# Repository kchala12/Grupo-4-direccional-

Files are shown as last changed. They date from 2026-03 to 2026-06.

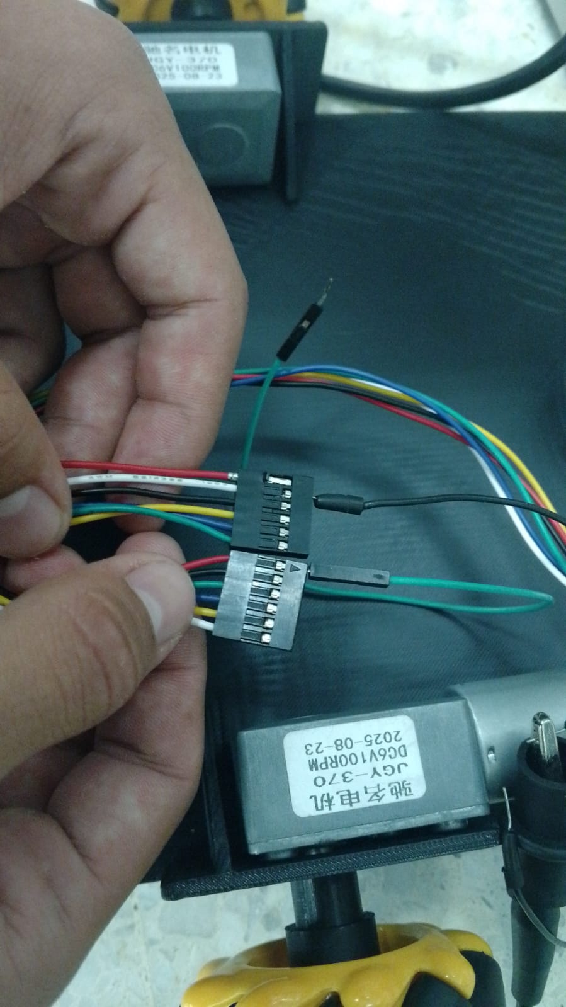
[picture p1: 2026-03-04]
Electronica/Imágenes Electrónica/motor defectuoso.jpeg

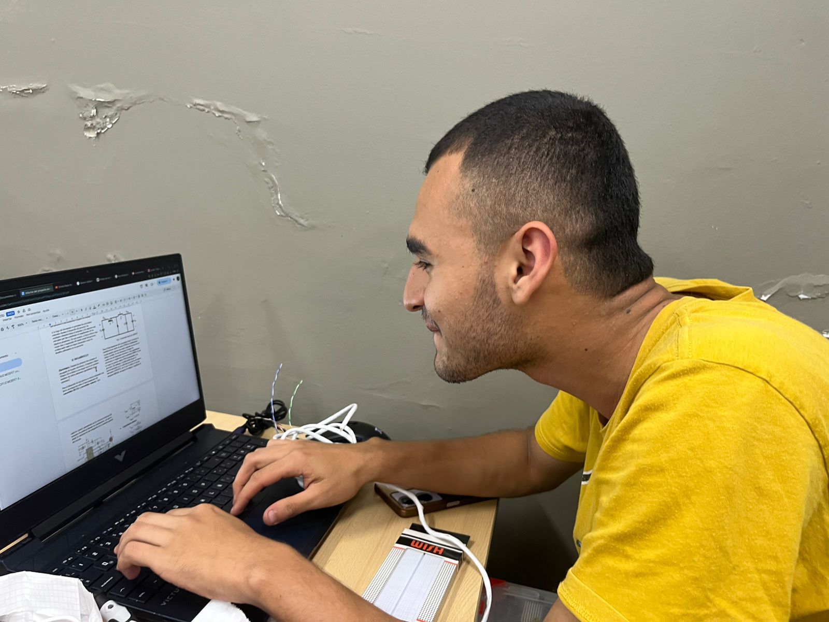
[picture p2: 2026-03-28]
Electronica/Imágenes Electrónica/TRABAJO CHALA.jpeg

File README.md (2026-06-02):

# Grupo-4-direccional

> **Robot Móvil Autónomo para Transporte Inteligente de Materiales**  
> Proyecto — Ingeniería Mecatrónica · Universidad Tecnológica de Pereira · 2026

---

## Descripción

Diseño y desarrollo de un **Vehículo Guiado Autónomo (AGV)** con visión artificial, capaz de transportar y descargar una carga de hasta **1 kg** a través de tres estaciones predefinidas, simulando operaciones logísticas en entornos industriales controlados.

El sistema utiliza **códigos QR** como referencias de navegación y una cámara **IMX219** para su detección en tiempo real, todo procesado sobre una **Raspberry Pi 5**.

---

## Objetivo

Desarrollar un robot funcional que complete de forma autónoma un ciclo de recolección y distribución de carga hacia tres estaciones destino con traccion diferencial, **sin intervención humana**, en un plazo de **16 semanas**.

---

##  Estructura del Repositorio

```
Grupo-4-direccional/
│
├── Documentacion/       # Matriz de documentos, informes y entregables
├── Electronica/         # Esquemas eléctricos, PCBs y firmware
├── Mecanica/            # Diseños CAD, planos y ensamblajes
├── src/                 # Código fuente principal (visión, navegación, control)
├── .gitignore
├── LICENSE
└── README.md
```
### 📁 [Documentacion](https://github.com/kchala12/Grupo-4-direccional-/tree/main/Documentacíon)
Contiene toda la documentación formal del proyecto: matriz de documentos, cronogramas, actas de reunión, informes de avance semanales y el informe final. También incluye presentaciones y entregables académicos requeridos por la universidad.
 
### 📁 [Electronica](https://github.com/kchala12/Grupo-4-direccional-/tree/main/Electronica)
Aquí se encuentran los esquemas eléctricos del sistema, diagramas de conexión de los componentes, diseños de PCB, selección y hoja de datos de los actuadores y drivers utilizados. También incluye el firmware de los microcontroladores encargados del control de motores y señales de los sensores.
 
### 📁 [Mecanica](https://github.com/kchala12/Grupo-4-direccional-/tree/main/Mecanica)
Contiene los diseños CAD del chasis del robot, planos técnicos de las piezas fabricadas o impresas en 3D, ensamblajes del sistema de tracción, soporte de carga y montaje de la cámara. 
 
### 📁 [src](https://github.com/kchala12/Grupo-4-direccional-/tree/main/src)
Código fuente principal del sistema autónomo. Incluye los módulos de visión artificial para la detección de códigos QR, algoritmos de navegación y control de trayectoria, lógica de gestión de estaciones y comunicación entre subsistemas. Todo desarrollado en Python sobre Raspberry Pi 5.
---

## 👥 Equipo

**Investigadores**
- Mateo Tabares Gil
- Federico Gómez Lotero
- Juan Sebastián Flórez Molina
- Kevin Andrés Chala González

**Director**
- Osiel Arbeláez Salazar

**Asesores**
- Angie Tatiana Rengifo Oviedo
- Carlos Andrés Rodríguez Pérez
- Edward Andrés González Ríos

---

## 🏛️ Institución

**Universidad Tecnológica de Pereira — Facultad de Tecnología — Febrero 2026**

---

## 📄 Licencia

Este proyecto está bajo la licencia especificada en el archivo [LICENSE](./LICENSE).

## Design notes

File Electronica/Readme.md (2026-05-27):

🔌 Electrónica — Diseño y Fabricación PCB

Esquemas, archivos de fabricación e imágenes del sistema electrónico del Robot Móvil Autónomo para Transporte Inteligente de Materiales
Ingeniería Mecatrónica · Universidad Tecnológica de Pereira · 2026

🗂️ Contenido de la Carpeta
📁 Imágenes Electrónica
Contiene imágenes de referencia relacionadas con el desarrollo electrónico del proyecto, tales como diagramas, capturas del diseño PCB, evidencias de montaje, conexiones y pruebas realizadas durante el desarrollo.
📁 PCB
Archivos del diseño de la tarjeta de circuito impreso (PCB). Incluye el esquemático del circuito, el layout de la placa, la lista de materiales (BOM) y los archivos de proyecto del software de diseño utilizado.

📑 Archivos .gbr — Gerber
Esta carpeta contiene los archivos Gerber (.gbr) utilizados para la fabricación de la tarjeta PCB. Estos archivos almacenan la información necesaria para el corte, perforación, pistas de cobre, máscara de soldadura y serigrafía de la placa electrónica.

⚠️ La versión aquí almacenada corresponde a los archivos enviados al fabricante en China para la producción de la PCB.

🛠️ Herramientas de Diseño
Los archivos de esta carpeta fueron desarrollados con herramientas de diseño electrónico. Se recomienda usar alguno de los siguientes programas para visualizarlos y editarlos:

KiCad — Diseño de PCB libre y gratuito
EasyEDA — Diseño online, compatible con fabricantes como JLCPCB
Altium Designer — Herramienta profesional de diseño electrónico
Gerber Viewer — Visualización rápida de archivos .gbr sin instalar nada

📌 Notas

Los archivos Gerber están listos para enviar directamente a fabricante.
Para modificar el diseño, usar los archivos fuente dentro de la carpeta PCB/.
Las imágenes en Imágenes Electrónica/ sirven como referencia visual para el ensamblaje y conexionado del sistema.

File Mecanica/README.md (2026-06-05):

# ⚙️ Mecánica — Diseño Estructural del Robot

> Diseños, planos y modelos CAD del **Robot Móvil Autónomo para Transporte Inteligente de Materiales**  
> Ingeniería Mecatrónica · Universidad Tecnológica de Pereira · 2026

---

## 🗂️ Contenido de la Carpeta

### 📁 acoples
Diseños y dibujos técnicos con cotas de los elementos de acople del robot. Incluye las piezas de unión entre el sistema de tracción y el chasis, adaptadores de motores y cualquier componente de transmisión mecánica. Los planos cuentan con acotación completa para su fabricación o impresión 3D.

### 📁 cuerpo carro
Modelos y diseños del cuerpo principal del robot (chasis). Contiene las iteraciones del diseño estructural del vehículo, incluyendo la distribución de componentes, soporte de carga, montaje de la cámara IMX219 y los últimos cambios aplicados al diseño del carro.

### 📁 objetos
Dibujos técnicos con cotas de piezas y objetos complementarios del ensamblaje. Incluye soportes, bases, brackets y demás elementos diseñados a medida para integrar los subsistemas electrónicos y mecánicos del robot.

---

## 🛠️ Herramientas de Diseño

Los archivos de esta carpeta fueron desarrollados con herramientas CAD. Se recomienda usar alguno de los siguientes programas para visualizarlos y editarlos:

- [Fusion 360](https://www.autodesk.com/products/fusion-360/) — Modelado 3D y simulación

---

## 📌 Notas

- Todas las piezas están diseñadas considerando una carga útil máxima de **1 kg**.
- Los dibujos técnicos incluyen cotas en milímetros (mm).
- Para piezas fabricadas por impresión 3D, verificar tolerancias antes de imprimir.

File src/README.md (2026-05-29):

# 💻 src — Código Fuente

> Módulos de software del **Robot Móvil Autónomo para Transporte Inteligente de Materiales**  
> Ingeniería Mecatrónica · Universidad Tecnológica de Pereira · 2026

---

## 🗂️ Contenido de la Carpeta

### 📁 .vscode
Configuración del entorno de desarrollo Visual Studio Code. Contiene ajustes del intérprete de Python, tareas de ejecución remota y configuración de depuración para trabajar directamente sobre la Raspberry Pi 5 y ESP-32.

### 📁 pruebas camara imx219
Scripts y recursos utilizados durante las pruebas de integración y calibración de la cámara **IMX219**. Incluye pruebas de captura, ajuste de resolución, enfoque y validación de la detección de códigos QR en distintas condiciones de iluminación.

### 📁 pruebas pasadas
Versiones anteriores de scripts y experimentos realizados durante el desarrollo. Sirve como historial de iteraciones previas del sistema de navegación, control de motores y detección visual, incluyendo las actualizaciones de los puntos de descarga.

---

## 📑 Archivos Principales

| Archivo | Descripción |
|---|---|
| `principal16.py` | Script principal del sistema. Ejecuta el ciclo autónomo completo: detección QR, navegación y descarga en las estaciones. **Punto de entrada del robot.** |
| `camara_detector27.py` | Módulo de visión artificial. Gestiona la captura de imágenes con la cámara IMX219 y la detección/decodificación de códigos QR en tiempo real. |
| `motor_control7.py` | Módulo de control de motores. Gestiona la velocidad, dirección y parada del sistema de tracción del robot según las instrucciones de navegación. |

---

## 🚀 Ejecución

### Requisitos previos

- Raspberry Pi 5 con Raspberry Pi OS (64-bit)
- Python 3.10+
- Cámara IMX219 conectada y habilitada (`raspi-config`)

### Instalar dependencias

```bash
pip install -r requirements.txt
```

### Calibrar encoders (primera vez)

```bash
python calibrar_encoders.py
```

### Ejecutar el sistema principal

```bash
python principal19.py
```

---

## 🧩 Arquitectura del Software

```
principal16.py
    ├── camara_detector27.py   →  Detección de códigos QR
    └── motor_control9.py      →  Control de motores y tracción
```

---

## 📌 Notas

- Los archivos están nombrados con versión numérica (ej. `principal16.py`) para llevar trazabilidad de iteraciones.
- Se recomienda ejecutar siempre desde la raíz de la carpeta `src/`.
- Para pruebas individuales de cada módulo, revisar la carpeta `pruebas pasadas/`.

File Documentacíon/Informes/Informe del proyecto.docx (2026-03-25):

Informe Progreso De Equipo

Mateo Tabares Gil, Juan Sebastian Flores Molina, Federico Gomez, Kevin Andres Chala Gonzalez

Ingeniería Mecatrónica, Universidad tecnológica de Pereira

Pereira, Colombia

Resumen — El presente informe tiene como objetivo presentar los avances del proyecto integrador en sus diferentes áreas de desarrollo, incluyendo los componentes mecánicos, electrónicos y de programación, así como sus respectivas integraciones y procesos asociados. Destacando los resultados obtenidos, las actividades realizadas y los aspectos relevantes que contribuyen al cumplimiento de los objetivos planteados.

Abstract— This report addresses the analysis, simulation, and physical assembly of a buck converter, designed to reduce an input voltage to a lower output level while maintaining high energy efficiency. It describes its theoretical operation, the fundamental equations governing its operation, and presents its software and hardware construction. The results verify the direct relationship between the duty cycle and the output voltage, confirming the converter's expected behavior.

I. INTRODUCCIÓN

El presente informe tiene como finalidad dar a conocer los avances alcanzados en el desarrollo del proyecto integrador, abordando de manera detallada cada una de sus áreas fundamentales. En este sentido, se describen los progresos en los componentes mecánicos, electrónicos y de programación, así como los procesos de integración que permiten el funcionamiento conjunto del sistema.

A lo largo del documento se presentan las actividades realizadas durante el desarrollo del proyecto, los resultados obtenidos hasta el momento y los aspectos más relevantes que han contribuido al cumplimiento de los objetivos propuestos. De esta manera, se busca ofrecer una visión clara y organizada del estado actual del proyecto, evidenciando tanto los logros alcanzados como los desafíos enfrentados en su ejecución.

II. DESARROLLO

Electrónica: Durante las primeras dos semanas, el responsable del área electrónica, el ingeniero Mateo Tabares Gil, se dedicó a la investigación de modelos similares de robots autónomos, con el propósito de analizar y comprender en profundidad su estructura, funcionamiento y principios de diseño. Este proceso incluyó la revisión de diversas fuentes de información, tanto institucionales como empresariales que permitió identificar las características e ideas para el concepto del robot autónomo.

A partir de la cuarta semana, y con base en los conocimientos adquiridos del análisis de proyectos previos, el equipo comenzó el proceso de desarrollo del código de control, apoyándose en diversos tutoriales, documentación técnica y hojas de datos (datasheets). Como resultado, se logró implementar una primera versión funcional del programa, la cual permitió el accionamiento básico de los motores previamente testeados por el ingeniero Flórez. Este avance facilitó que, durante la quinta semana, dicho código fuera integrado exitosamente con los motores del sistema.

Posteriormente, entre la sexta y séptima semana, la responsabilidad del área electrónica fue asumida por el ingeniero Juan Sebastián Flores Molina, bajo la supervisión del ingeniero Mateo Tabares Gil. En esta etapa, el objetivo principal consistió en emplear el puente H suministrado por el laboratorio junto con la ESP32, con el fin de lograr un control adecuado del movimiento de la base del vehículo. Sin embargo, durante un ensayo realizado en la semana seis, se identificó una dificultad al intentar integrar el segundo motor al sistema mediante la ESP32, lo que llevó a realizar una consulta al ingeniero Carlos Andrés Rodríguez, quien recomendó efectuar una revisión exhaustiva del código.

Adicionalmente, al inicio de la semana siete se presentó una falla crítica en el puente H, cuyo circuito integrado se quemó, dejándolo fuera de funcionamiento. Tras la respectiva revisión, se determinó que la causa del daño estaba asociada a un defecto en el encapsulado de fábrica. Debido a esta situación, el ingeniero Mateo Tabares Gil gestionó la adquisición de un nuevo puente H. Una vez realizada la nueva conexión e instalado el componente de reemplazo, se logró integrar correctamente el segundo motor al sistema de control. Cabe destacar que la comunicación entre la Raspberry Pi 5 y la ESP32 continuó operando sin inconvenientes. Finalmente, al finalizar la semana siete, se llevaron a cabo pruebas del prototipo, obteniendo un funcionamiento adecuado y sin fallas.

Programación: El área de programación se encuentra a cargo del ingeniero Juan Sebastián Flores Molina. Durante las primeras semanas, el ingeniero Flores, en conjunto con el ingeniero Federico Gómez Lotero, se dedicó a la investigación de materiales y al análisis de diferentes alternativas para el diseño de una base funcional del proyecto autónomo, tomando como referencia modelos comerciales y desarrollos previos.

Posteriormente, durante las semanas cuatro y cinco, se llevaron a cabo pruebas con motores y sus respectivos encoders, con el objetivo de evaluar su desempeño e integración en el sistema. Sin embargo, a mediados de la semana cuatro se presentó un inconveniente, ya que los motores no lograban iniciar su funcionamiento a pesar de haberse realizado las conexiones conforme a lo indicado en sus hojas de datos. Ante esta situación, se solicitó la asesoría del ingeniero Carlos Andrés Rodríguez, quien, tras realizar un diagnóstico, determinó que el cableado de los motores presentaba inconsistencias de fábrica. Como solución, recomendó verificar de manera individual cada una de las conexiones.

Gracias a esta intervención, el equipo procedió a realizar un análisis comparativo utilizando un motor con cableado correcto, lo que permitió identificar con precisión las entradas de voltaje, la alimentación de los encoders y sus respectivas señales en los motores defectuosos. A partir de esta corrección, las pruebas de funcionamiento de los motores junto con sus encoders se desarrollaron de manera satisfactoria.

Finalmente, durante las semanas seis y siete, el área de programación se enfocó en la optimización y ajuste del código previamente desarrollado por el ingeniero Mateo Tabares Gil, proceso que se llevó a cabo bajo la supervisión del responsable del área, garantizando así un mejor desempeño del sistema.

Mecánica: El área de mecánica se encuentra a cargo del ingeniero Federico Gómez Lotero, quien, al igual que sus compañeros de equipo, dedicó las primeras tres semanas a la investigación de proyectos previos y al análisis de diferentes diseños de referencia. Gracias a su experiencia previa en el diseño de chasis en proyectos similares, y con el apoyo del ingeniero Edward Andrés González Ríos, se logró consolidar un amplio sustento técnico que orientó el desarrollo de la estructura mecánica.

Durante las semanas cuatro y cinco, el diseño de la base avanzó de manera significativa, permitiendo la obtención de un modelo preliminar a mediados de la semana cuatro. Posteriormente, con la intervención del ingeniero Edward, se gestionó la impresión 3D de la base, la cual estuvo disponible para su evaluación hacia el miércoles de la semana seis. En el proceso de revisión, específicamente en los puntos de anclaje para las ruedas omnidireccionales, el ingeniero Carlos Andrés Rodríguez sugirió la implementación de soportes especializados debido a las características geométricas de los motores. Esta recomendación permitió mejorar notablemente la estabilidad y funcionalidad de la base.

Finalmente, durante las semanas seis y siete, las ideas y aportes de los diferentes integrantes del equipo contribuyeron al desarrollo de un modelo más robusto y estable. Bajo la supervisión del ingeniero Federico Gómez Lotero, y con el apoyo en el proceso de ensamblaje por parte de Kevin Chala, se logró construir una base capaz de integrar adecuadamente los componentes electrónicos desarrollados por el ingeniero Mateo Tabares Gil. Adicionalmente, en la semana siete se optimizó la distribución del espacio interno, permitiendo la incorporación eficiente de la batería y facilitando que el robot autónomo operará sin la necesidad de estar conectado a una fuente de alimentación externa.

III. Resultados

A medida que se fueron obteniendo resultados, se evidenció un adecuado cumplimiento del cronograma y de las bitácoras de seguimiento, manteniendo un desarrollo organizado y dentro de los tiempos establecidos. No obstante, se presentaron leves retrasos asociados principalmente a la disponibilidad de algunos componentes físicos y a inconvenientes surgidos durante las fases de prueba, tal como se ha descrito previamente en el informe.

A pesar de estas dificultades, el proyecto ha logrado avanzar de manera continua y estructurada, garantizando un desarrollo sostenible y coherente con los objetivos planteados.

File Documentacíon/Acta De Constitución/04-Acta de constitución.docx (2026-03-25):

# Desarrollo de un robot móvil autónomo para el transporte inteligente de materiales.

Mateo Tabares Gil

Federico Gómez Lotero

Juan Sebastián Flórez Molina

Kevin Andrés Chala Gonzalez

Director del Programa Osiel Arbeláez Salazar

Asesores

Angie Tatiana Rengifo Oviedo

Carlos Andrés Rodríguez Pérez

Edward Andrés Gonzalez Ríos

Universidad Tecnológica De Pereira

Facultad de Tecnología Programa de Ingeniería Mecatrónica

Febrero 17 de 2026

# Resumen

El presente documento tiene como propósito documentar el desarrollo de un vehículo guiado autónomo (AGV) con visión artificial, diseñado para realizar un recorrido a través de tres estaciones. Durante su trayectoria, el sistema transporta y descarga una carga de hasta 1 kg en puntos específicos, con el fin de simular su funcionamiento en un entorno controlado.

Palabras clave: Vehículo guiado autónomo, Visión artificial, Robot móvil, Transporte de materiales. Navegación autónoma

# Abstract

This document aims to describe the development of an Automated Guided Vehicle (AGV) with computer vision capabilities, designed to perform a predefined route through three stations. During its trajectory, the system transports and unloads a load of up to 1 kg at specific points, in order to simulate its operation within a controlled environment.

Keywords: Artificial visión, QC, Controlled, Industrial, Robot

# Introducción

En el contexto actual de la automatización industrial, la implementación de sistemas robóticos autónomos se ha convertido en una solución estratégica para optimizar procesos, mejorar la eficiencia operativa y reducir la intervención humana en tareas repetitivas o de alto riesgo. La integración de tecnologías como la visión artificial y los sistemas de identificación mediante códigos QR ha permitido desarrollar mecanismos de guiado más precisos y adaptables a entornos controlados.

El presente documento expone el Acta de Constitución del proyecto orientado al diseño y desarrollo de un robot móvil con seguimiento de trayectoria para uso industrial, utilizando códigos QR como referencia de navegación y haciendo uso de visión artificial como herramienta principal de detección y procesamiento de obstáculos. Este proyecto busca integrar conocimientos en electrónica, programación, control y sistemas embebidos, con el fin de proponer una solución tecnológica aplicable a bodegas, plantas de producción y espacios industriales controlados.

A lo largo del documento se describen los elementos fundamentales que dan inicio formal al proyecto, incluyendo su propósito, alcance, objetivos, recursos y consideraciones iniciales para su ejecución.

# Propósito

El propósito del presente proyecto es diseñar y desarrollar un robot móvil con capacidad de seguimiento de trayectoria mediante la lectura y procesamiento de códigos QR, orientado a su aplicación en entornos industriales controlados. El sistema integrará tecnologías de visión artificial, control de movimiento, con el fin de permitir la navegación autónoma y la ejecución eficiente de tareas de transporte o desplazamiento dentro de bodegas.

Así mismo, el proyecto busca consolidar la aplicación práctica de conocimientos multidisciplinarios en electrónica, robótica y automatización, promoviendo el desarrollo de una solución tecnológica que contribuya a la optimización de procesos industriales y al fortalecimiento de competencias técnicas en el área de la ingeniería.

# Justificación

La creciente demanda de eficiencia, precisión y reducción de costos en los entornos industriales ha impulsado la adopción de sistemas automatizados que optimicen los procesos internos de transporte y logística. En este contexto, la robótica móvil se posiciona como una herramienta clave para mejorar la productividad y minimizar errores asociados a la intervención humana en tareas repetitivas o de desplazamiento continuo dentro de bodegas y plantas de producción.

El desarrollo de un robot móvil con seguimiento de trayectoria mediante códigos QR y visión artificial se justifica como una solución tecnológica viable y adaptable para entornos controlados, donde la navegación puede estructurarse a partir de referencias visuales previamente

establecidas. El uso de códigos QR como puntos de guía permite implementar un sistema de orientación preciso, de bajo costo y fácil configuración, lo que representa una alternativa eficiente frente a otros métodos de navegación más complejos o costosos.

Desde el punto de vista académico, el proyecto integra conocimientos multidisciplinarios en áreas como electrónica, programación, control automático, procesamiento de imágenes y sistemas embebidos, favoreciendo el desarrollo de competencias técnicas aplicadas. Además, promueve la comprensión práctica de conceptos relacionados con automatización industrial y robótica, fortaleciendo la capacidad de diseño, análisis y resolución de problemas tecnológicos.

Finalmente, este proyecto sienta las bases para futuras mejoras orientadas a incrementar el nivel de autonomía del sistema, ampliar su aplicabilidad en distintos entornos productivos y contribuir al avance de soluciones innovadoras dentro del ámbito industrial.

# Estado Del Arte

En la robótica autónoma con visión artificial, proyectos e investigaciones anteriores han llevado a avances en plataformas embebidas como Raspberry Pi, para navegación y percepción en entornos controlados, Por ejemplo, Según Gallardo Gómez, L. En el documento Desarrollo de un robot de fútbol con detección de pelotas (2017) contiene la construcción de un robot soccer con detección de pelotas Usando OpenCV y segmentación HSV, enfocado en tracción omnidireccional y control en tiempo real para torneos. En otro documento Gallardo Gómez, L. Aplicación de visión por computador y machine learning al guiado de un robot móvil basado en Raspberry Pi (Trabajo de Fin de Grado) (2017). implementó un coche autónomo con CNN (MobileNetV2) capaz de percibir su entorno mediante una cámara y tomar decisiones de movimiento utilizando algoritmos de visión por computador y machine learninde giros en base a imágenes, Otros proyectos como el de Martínez Martínez, A. Construcción de un coche de conducción autónomo robótico (2022), Gómez Patiño, D. A. Diseño e implementación de un robot móvil autónomo para el transporte de materiales (2019) y Ferreira Neto, N. A. (2022). Visual-based perception for autonomous vehicles in off-road environment using deep learning. Estos trabajos demuestran que sistemas de bajo costo en superficies planas son viables, pero nos muestran las limitaciones en precisión de trayectorias específicas, latencia para decodificación en tiempo real y generalización a protocolos industriales, como códigos QR. El presente proyecto se justifica al diseñar e implementar un robot móvil autónomo que supera limitaciones mediante objetivos con la metodología SMART

# Antecedentes

La robótica móvil constituye una rama de la ingeniería que se encarga del diseño y desarrollo de sistemas capaces de desplazarse de manera autónoma dentro de un entorno determinado. Estos sistemas combinan elementos de electrónica, control automático, programación y mecánica, permitiendo la ejecución de tareas específicas sin intervención humana directa.

Uno de los componentes fundamentales en la robótica móvil es el sistema de navegación, el cual puede implementarse mediante diferentes técnicas como seguimiento de línea, sensores de proximidad, sistemas de posicionamiento global o tecnologías basadas en visión artificial. En entornos industriales controlados, donde las condiciones del entorno son estructuradas y previsibles, la navegación asistida por marcadores visuales representa una alternativa eficiente y de bajo costo.

La visión artificial es una tecnología que permite a los sistemas computacionales interpretar información visual capturada mediante cámaras, procesando imágenes para extraer datos relevantes. En aplicaciones industriales, se utiliza para inspección de calidad, identificación de objetos, control de procesos y sistemas de guiado automatizado. Su integración en robots móviles facilita la toma de decisiones basada en información visual en tiempo real.

Por otra parte, los códigos QR (Quick Response) son matrices bidimensionales capaces de almacenar información codificada, la cual puede ser interpretada mediante algoritmos de procesamiento de imagen. Su uso en sistemas de navegación permite establecer puntos de referencia dentro de un espacio físico, proporcionando información de ubicación, instrucciones de movimiento o identificación de rutas.

La combinación de robótica móvil, visión artificial y códigos QR posibilita el desarrollo de sistemas de desplazamiento autónomo aplicables a procesos logísticos internos, como transporte de materiales en bodegas o plantas de producción. Esta integración tecnológica ofrece ventajas en términos de flexibilidad, precisión y reducción de costos frente a soluciones más complejas como sistemas basados en sensores láser o mapeo avanzado.

# Objetivos

S – Específico: Desarrollar un robot autónomo con capacidad de carga útil de 1 kilogramo, diseñado para ejecutar un ciclo logístico que comprenda la recolección de carga en una estación de origen y la distribución autónoma hacia tres estaciones de destino predefinidas

M – Medible: El desempeño del robot será evaluado mediante la tasa de éxito en la competición del ciclo de cargue y descargue, considerando 100% de misiones completadas sin intervención humana, transportando efectivamente la carga de 1 kilogramo hacia cada una de las tres estaciones destino.

A – Alcanzable: El desarrollo se llevará a cabo con tecnologías de navegación autónoma y sistemas de transporte de carga ampliamente documentados, utilizando componentes de acceso comercial y herramientas de software de código abierto, lo cual hace viable su implementación dentro del marco académico del proyecto.

R – Relevante: El proyecto responde a la creciente necesidad de automatización en procesos logísticos, aportando una solución práctica que integra navegación autónoma, percepción del entorno y manipulación de carga, contribuyendo al avance del conocimiento en robótica aplicada.

T – Con tiempo definido: El prototipo funcional deberá ser diseñado, ensamblado y validado en un entorno controlado en un plazo de 16 semanas, con entregas parciales en las semanas 3, 5, 7, 11, 13, 15 y 16

# Requisitos de Alto nivel

Requisitos Técnicos

1. El robot móvil deberá ser capaz de desplazarse de manera autónoma en un entorno industrial controlado.
2. Trasladar una carga de 1 kg de un punto de carga a 1 o máximo 3 puntos de descarga.El sistema deberá integrar una cámara para la captura de imágenes en tiempo real, permitiendo la detección y decodificación de códigos QR.
3. El algoritmo de procesamiento de imágenes deberá identificar correctamente los códigos QR dentro del campo de visión del robot.
4. El robot deberá implementar un sistema de tracción diferencial con la ayuda de dos ruedas omnidireccionales.
5. El sistema de control deberá garantizar estabilidad y precisión en el seguimiento de trayectoria.
6. El robot deberá operar con una fuente de alimentación autónoma (batería recargable).
7. El sistema deberá ser capaz de funcionar en superficies planas dentro de un entorno estructurado.

# Requisitos de Gestión

1. El proyecto deberá desarrollarse dentro del cronograma académico establecido.
2. Se deberá documentar cada fase del proyecto (diseño, implementación, pruebas y validación).
3. El equipo de trabajo deberá asignar roles y responsabilidades claras para cada integrante.
4. Se deberán realizar pruebas de validación antes de la entrega final del prototipo.
5. Se deberá presentar un informe final que incluya resultados, análisis y conclusiones.

Alcance inicial y exclusivo

El presente proyecto contempla el diseño, desarrollo e implementación de un robot móvil autónomo capaz de realizar seguimiento de trayectoria mediante la detección y procesamiento de códigos QR en un entorno industrial controlado.

El alcance del proyecto consta de:

- El diseño mecánico de la estructura del robot móvil.
- La implementación del sistema de tracción y control de movimiento.
- La integración de una cámara para la captura de imágenes en tiempo real.
- El desarrollo del sistema de visión artificial para la detección y decodificación de códigos QR.
- La programación del algoritmo de navegación está basada en la información obtenida de los códigos QR.
- La integración de los componentes electrónicos y del sistema embebido.
- La realización de pruebas de funcionamiento en un entorno controlado simulado.
- La documentación técnica y académica correspondiente al desarrollo del proyecto.

Exclusión del proyecto

- La integración con sistemas industriales externos como ERP o software de gestión logística.
- El diseño de producción en serie o comercialización del prototipo.
- La implementación de sistemas de inteligencia artificial avanzada para la toma de decisiones complejas.
- La operación en entornos no estructurados o exteriores.

Presupuesto Estimado y Materiales

Tabla 1

Precios de materiales

Nombre | Precio | Cantidad | Enlace | Imágenes | Total, sin IVA | Valor Total
ESP32 | $26.306 | 1 | Tarjeta De Desarrollo Esp Wroom 32 Esp322 Wifi Bluetooth GENERICO | falabella.com (https://www.falabella.com.co/falabella-co/product/129449389/Tarjeta-De-Desarrollo-Esp-Wroom-32-Esp322-Wifi-Bluetooth/129449390) | | $22.106 | $26.306
Raspberry Pi 5 (8GB) | $491.852 | 1 | Raspberry Pi 5 8GB RPI5-8GB-SINGLE CON DISIPADOR (EXT IVA) (https://www.vistronica.com/board-de-desarrollo/raspberry-pi/raspberry-pi-5-8gb-rpi5-8gb-single-con-disipador-ext-iva-detail.html) | | $413.321 | $491.852
Filamento PLA 1kg | $60.000 | 1 | https://ari3d.co/product/filamento-anycubic-pla-negro/ | | $50.421 | $60.000
PCB | $20.000 | 1 | https://www.pcbcart.com/ | | $16.807 | $20.000
Protoboard | $12.000 | 1 | https://dualtronica.com/miscelanea/625-protoboard-generica-mb-102-830-puntos.html | | $10.084 | $12.000
Jumpers | $8.000 | 1 | https://dualtronica.com/cables-y-pines/42-cables-dupont-jumper-macho-macho.html | | $6.723 | $8.000
Cable UTP | $3.000 | 1 | Metro De Cable UTP Categoría 5E, 100% Cobre (https://dualtronica.com/cables-y-pines/256-metro-de-cable-utp-categoria-5e-100-cobre-.html) | | $2.521 | $3.000
Cámara IMX219 | $245.000 | 1 | Módulo Cámara Infrarroja 8mp Imx219-160ir Para Jetson Nano | Cuotas sin interés (https://articulo.mercadolibre.com.co/MCO-928922399-modulo-camara-infrarroja-8mp-imx219-160ir-para-jetson-nano-_JM) | | $205.882 | $245.000
Motores JGY 370 (2 und) | $69.706 | 2 | Motorreductor Jgy370 Con Encoder Y Engranaje Metálico | Cuotas sin interés (https://www.mercadolibre.com.co/dc-24v-gear-motor-jgy370-encoder-reduction-full-metal/p/MCO2027613074) | | $117.152 | $139.412
Cable Serial USB | $24.600 | 1 | Cable Usb A 2.0 A Usb C 1M Con Revestimiento De Aluminio (Negro) (https://www.exito.com/cable-usb-a-20-a-usb-c-1m-con-revestimiento-de-aluminio-negro-103746966-mp/p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) | | $20.672 | $24.600
Ruedas omnidireccionales (2) | $15.000 | 2 | Llanta Omnidireccional 60mm Derecha, para motorreductor amarillo (https://dualtronica.com/llantas-para-robotica/888-llanta-omnidireccional-60mm-derecha-para-motorreductor-amarillo.html) | | $25.210 | $30.000
Nombre | Precio | Cantidad | Enlace | Imágenes | Total, sin IVA | Valor Total
Puente H TB 6612 | $13.600 | 1 | TB6612FNG Puente H Driver Controlador Motor Dual 1A Arduino GENERICO | falabella.com (https://www.falabella.com.co/falabella-co/product/140481742/tb6612fng-puente-h-driver-controlador-motor-dual-1a-arduino/140481743) | | $11.428 | $13.600
Tornillos M3 (22 und) | $29.100 | 22(710) | https://www.amazon.com/-/es/dp/B0F3JKMZLN | | $24.454 | $29.100
Tornillos M4 (4 und) | $3.000 | 4(2) | Tornillo Bristol M4-0.7 X20 2 Undidades Fixser - Homecenter.com.co (https://www.homecenter.com.co/homecenter-co/product/593018/tornillo-bristol-m4-07-x20-2-undidades-fixser/593018/) | | $5.042 | $6.000
Rueda tipo balín | $5.000 | 2 | https://dualtronica.com/inicio/385-rueda-loca-metalica-para-robotica.html | | $8.403 | $10.000
Batería LiPo Turnigy 11.1V 5000mAh | $210.000 | 1 | https://demosspro.com/806-bateria-lipo-turnigy-111-v-3s-5000mah-20-30c-xt60.html | | $176.471 | $210.000

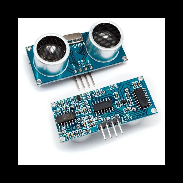
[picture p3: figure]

Sensor ultrasonido Hc-sr04 | $8.000 | 2 | https://dualtronica.com/sensores/71-sensor-ultrasonido-hc-sr04.html | | $13.120 | $16.000
Total | $1.258.164 | | | | $1.152.777 | $1.372.870

# 2. Recursos Humanos

Tabla 2.

Presupuesto estimado de los colaboradores

Nombre | Costo (Por Hora) | Tiempo (En Horas) | Total
Angie Tatiana Rengifo Oviedo | $ 150,000 | 64 | $ 9,600,000
Carlos Andrés Rodríguez Pérez | $ 130,000 | 96 | $ 12,480,000
Edward Andrés Gonzalez Ríos | $ 190,000 | 96 | $ 18,240,000
Mateo Tabares Gil | $ 40,000 | 256 | $ 10,240,000
Federico Gómez Lotero | $ 40,000 | 256 | $ 10,240,000
Juan Sebastián Flórez Molina | $ 40,000 | 256 | $ 10,240,000
Kevin Andrés Chala Gonzalez | $ 40,000 | 256 | $ 10,240,000
Total | | | $ 81,280,000

Nota: Tabla la cual relaciona los precios por hora que manejan los ingenieros de consulta.

# 3. Recursos Tecnológicos

- Impresora 3D Any Cubic Kobra 3 Combo
- Estación De Soldadura

# 4. Licencias de Software (Costo asumido por la Universidad)

      - Fusion 360 – Licencia Educativa.

Costo comercial referencial aproximado: $545 USD/año o $1.994.846 COP/año por usuario

      - GitHub (GitHub Education / GitHub Pro Student).

Costo comercial referencial aproximado: $4 USD/mes o 14.641COP/mes lo que en total por los cuatro meses de trabajo serían $16 USD o 58.516COP por usuario (plan Pro).

TOTAL = $2.053.362 COP

# 5. Recursos Físicos

  5.1 Recursos Físicos Institucionales
      - Uso del salón/laboratorio: $509.000 COP por mes por lo tanto serían 2.036.000 COP
      - Espacio para pruebas de navegación en entorno controlado.

# 5.2 Recursos Físicos Propios del Equipo

Angie Tatiana Rengifo Oviedo

2026-03-03 17:36:42

Los recursos de información son las bases de datos de donde se genera la información. Si son gratuitos tienen costo 0, de lo contrario identificar el valor total para el proyecto.

      - Herramientas de ensamblaje (destornilladores, llaves, pinzas, etc.).
      - Consumo aproximado durante impresión: entre 350W y 500W, por ende el consumo promedio estimado: 0.45 kWh por hora de impresión y el costo promedio estimado: 405 COP/Hora, aproximadamente se ha planteado que lo máximo que se demorara imprimiendo las piezas del robot incluyendo pruebas sería 36 horas lo que sería $14.580 COP.

TOTAL = $2.050.742COP

El presupuesto total estimado para el desarrollo del proyecto se encuentra entre $72.999.277 COP, incluyendo los costos de los componentes electrónicos, la estructura mecánica, el material utilizado para impresión 3D (PLA) y el consumo energético generado durante el proceso de fabricación y ensamblaje, los recursos humanos, las licencias entre otros.

Riesgos Iniciales del Proyecto

Todo proyecto está expuesto a situaciones que pueden afectar su desarrollo, cumplimiento de objetivos, cronograma, costos o calidad. A continuación, se identifican los riesgos iniciales más relevantes junto con su nivel de afectación y las estrategias propuestas para su mitigación.

Riesgos Técnicos

Fallas tecnológicas y posibles errores en software: hardware o herramientas utilizadas para el desarrollo del proyecto que puedan retrasar la implementación.

Mitigación: Realizar pruebas periódicas de los componentes, mantener copias de seguridad del código y contar con proveedores alternativos de hardware.

Problemas de integración: Dificultades al integrar diferentes sistemas, plataformas o componentes del proyecto.

Mitigación: Definir protocolos de comunicación estandarizados desde las etapas tempranas del diseño y realizar pruebas de integración de forma incremental.

Cambios en los requerimientos: Modificaciones en los requisitos inicialmente definidos que impliquen retrabajo y ajustes en el cronograma.

Mitigación: Establecer un proceso formal de control de cambios y documentar todos los requisitos desde el inicio del proyecto.

# Riesgos Externos

Factores externos imprevistos

Situaciones externas como cambios normativos, problemas económicos o eventos externos que puedan afectar el desarrollo del proyecto.

# Dependencia de terceros: Retrasos ocasionados por proveedores o entidades externas involucradas en el proyecto.

Mitigación: Tener una red de apoyo con más de un proveedor donde se pueda hacer un cambio rápido en situaciones imprevistas.

# Referencias Bibliográficas

Gallardo Gómez, L. (2017). Desarrollo de un robot de fútbol con detección de pelotas mediante visión artificial. Universidad de Sevilla, Escuela Técnica Superior de Ingeniería.

Gallardo Gómez, L. (2017). Aplicación de visión por computador y machine learning al guiado de un robot móvil basado en Raspberry Pi. Universidad de Sevilla, Escuela Técnica Superior de Ingeniería.

Martínez Martínez, A. (2022). Construcción de un coche de conducción autónomo robótico. Universidad Politécnica de València.

Gómez Patiño, D. A. (2019). Diseño e implementación de un robot móvil autónomo para el transporte de materiales. Universidad Tecnológica de Pereira.

Ferreira Neto, N. A. (2022). Visual-based perception for autonomous vehicles in off-road environment using deep learning. Programa de Pós-Graduação em Engenharia Elétrica.

DESARROLLO DE UN VEHÍCULO AUTONOMO 2

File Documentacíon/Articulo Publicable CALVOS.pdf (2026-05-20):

Desarrollo iterativo de un robot móvil autónomo para logística industrial: registro de

avances del proyecto C.A.L.V.O.S.

Iterative development of an autonomous mobile robot for industrial logistics: progress report

of the C.A.L.V.O.S. project

Mateo Tabares Gil

Ingeniero Mecatrónico (en formación), Universidad Tecnológica de Pereira, Pereira, Colombia

Mateo.tabares@utp.edu.co,ORCID 0009-0008-1649-3352

Federico Gómez Lotero

Ingeniero Mecatrónico (en formación), Universidad Tecnológica de Pereira, Pereira, Colombia

federico.gomez@utp.edu.co, ORCID 0009-0006-2321-7837

Juan Sebastián Flórez Molina

Ingeniero Mecatrónico (en formación), Universidad Tecnológica de Pereira, Pereira, Colombia

juan.florez4@utp.edu.co, ORCID 0009-0000-4719-9799

Kevin Andrés Chala González

Ingeniero Mecatrónico (en formación), Universidad Tecnológica de Pereira, Pereira, Colombia

kevin.chala@utp.edu.co, ORCID 0009-0001-2950-7660

Director: Osiel Arbeláez Salazar

Asesores: Angie Tatiana Rengifo Oviedo, Carlos Andrés Rodríguez Pérez, Edward Andrés

González Ríos

Resumen

El presente artículo documenta el proceso iterativo de diseño, construcción y validación del robot

móvil autónomo C.A.L.V.O.S. (Control Autónomo Logístico Vehicular Optimizado de

Suministros), desarrollado durante 18 semanas en el Programa de Ingeniería Mecatrónica de la

Universidad Tecnológica de Pereira. A partir del registro sistemático en bitácoras de

seguimiento, se narran los avances logrados semana a semana en las áreas mecánica, electrónica

y de programación, así como los imprevistos técnicos enfrentados y las acciones correctivas

implementadas. El sistema, basado en una Raspberry Pi 5, un ESP32, la librería OpenCV y

navegación por códigos QR, alcanzó velocidades de 1,8 km/h en línea recta y completó de forma

autónoma el ciclo logístico de transporte de 1 kg entre tres estaciones de destino, cumpliendo la

totalidad de los indicadores clave de desempeño planificados.

Palabras clave: robot móvil autónomo, desarrollo iterativo, bitácora de proyecto, visión

artificial, AGV.

Abstract

This article documents the iterative design, construction, and validation process of the

C.A.L.V.O.S. autonomous mobile robot (Optimized Autonomous Vehicular Logistic Supply

Control), developed over 18 weeks at the Mechatronics Engineering Program of the Universidad

Tecnológica de Pereira. Drawing on systematic logbook records, it narrates the week-by-week

progress achieved in the mechanical, electronic, and programming domains, as well as the

technical setbacks encountered and corrective actions taken. The system, based on a Raspberry

Pi 5, an ESP32, the OpenCV library, and QR code navigation, reached speeds of 1.8 km/h on straight tracks and autonomously completed the logistics cycle of transporting a 1 kg load to

three destination stations, meeting all planned key performance indicators.

Keywords: autonomous mobile robot, iterative development, project logbook, artificial vision,

AGV.

### 1. Introducción

La automatización de procesos logísticos internos en bodegas y plantas industriales representa

uno de los focos de mayor crecimiento en la robótica móvil contemporánea. Los Vehículos de

Guiado Autónomo (AGV) han evolucionado desde sistemas de guiado magnético hacia

soluciones basadas en percepción visual, lo que ha reducido significativamente sus costos de

implementación y ha abierto la puerta a desarrollos académicos funcionales (Gómez Patiño,

2019; Amaguaña Moreta et al., 2023).

El proyecto C.A.L.V.O.S. Surge en este contexto como una propuesta de formación integral para

estudiantes de Ingeniería Mecatrónica, con el objetivo de diseñar e implementar un robot móvil

autónomo capaz de ejecutar ciclos logísticos de transporte de materiales en un entorno

controlado, utilizando visión artificial y códigos QR como sistema de navegación. A diferencia

de los artículos de resultados finales, el presente trabajo documenta el proceso mismo de

desarrollo: las decisiones técnicas tomadas semana a semana, los imprevistos enfrentados y las

estrategias de resolución adoptadas por el equipo.

Este enfoque narrativo e iterativo permite visibilizar aspectos del proceso de ingeniería que

habitualmente permanecen invisibles en la literatura científica, tales como las fallas de

componentes durante la integración, los diseños mecánicos motivados por problemas de estabilidad y los procesos de diagnóstico colaborativo con los asesores del proyecto. Se busca así

contribuir a la comprensión de los desafíos reales que enfrenta un equipo de estudiantes al

desarrollar un sistema robótico desde cero dentro del marco académico.

### 2. Metodología

El proyecto se estructuró siguiendo los lineamientos del estándar PMBOK del Project

Management Institute (2021), con una planificación inicial de 16 semanas organizada en fases

secuenciales: constitución del proyecto, diseño mecánico y electrónico, implementación del

sistema de visión artificial, integración general y validación. Cada fase fue documentada

mediante bitácoras de seguimiento elaboradas por el equipo, las cuales registraron los objetivos

planificados, las actividades ejecutadas, los desafíos encontrados, las acciones correctivas

implementadas y el estado de los entregables.

La investigación de antecedentes realizada durante las primeras semanas tomó como referentes

trabajos previos en navegación autónoma basada en Raspberry Pi (Gallardo Gómez, 2017),

construcción de vehículos robóticos de bajo costo (Martínez Martínez, 2022) y sistemas de

transporte autónomo en entornos industriales (Gómez Patiño, 2019). Estos trabajos orientaron las

decisiones de diseño del equipo en cuanto a la plataforma de cómputo, el método de navegación

y la arquitectura de control.

La arquitectura técnica del sistema se definió en torno a tres subsistemas interdependientes: el

mecánico (chasis, tracción diferencial y soporte de carga), el electrónico (Raspberry Pi 5 como

unidad central, ESP32 como controlador de bajo nivel, driver TB6612FNG, sensores HC-SR04 y

cámara IMX219) y el de software (algoritmos de navegación en Python con OpenCV para

seguimiento de línea por segmentación de color y decodificación QR en tiempo real). El presente artículo organiza el recuento de avances por grupos de semanas, en correspondencia con los

períodos de reporte de las bitácoras.

### 3. Resultados y discusión

### 3.1 Semanas 4 y 5: investigación, diseño y primeras pruebas de motores

Durante las semanas 4 y 5, las tres áreas del equipo iniciaron simultáneamente sus primeras

actividades concretas. En mecánica, Federico Gómez Lotero comenzó el diseño del chasis en

Fusion 360, obteniendo un modelo preliminar funcional hacia mediados de la semana 4. En

electrónica, Mateo Tabares Gil llevó a cabo las primeras conexiones de los motores JGY-370 con

encoder; sin embargo, los motores no respondían al encendido a pesar de seguir fielmente las

especificaciones de sus hojas de datos. Tras consultar con el asesor Carlos Andrés Rodríguez, se

identificó que el cableado de los motores presentaba inconsistencias de fábrica en la asignación

de señales. La solución consistió en realizar un análisis comparativo con un motor de referencia

con cableado correcto, lo que permitió identificar las entradas de voltaje, la alimentación de los

encoders y sus señales en cada motor. Esta corrección fue determinante para que las pruebas de

funcionamiento de los motores con encoder se desarrollaran satisfactoriamente al cierre de la

semana 5. En programación, Juan Sebastián Flórez Molina implementó una primera versión del

código de control de motores, que fue integrada con éxito durante esta misma semana.

### 3.2 Semanas 6 y 7: construcción del chasis, diseño de PCB y arranque del vehículo

La semana 6 marcó el inicio de la fase de construcción. Con la intervención del asesor Edward

González Ríos, se gestionó la impresión 3D del chasis en PLA, que quedó disponible para

evaluación a mediados de la semana. Durante la revisión, el asesor Carlos Rodríguez recomendó

implementar soportes especializados en los puntos de anclaje de las ruedas omnidireccionales,

dado que las dimensiones de los motores generaban inestabilidad en la base. Esta recomendación

fue acogida y los soportes rediseñados e impresos oportunamente.

En electrónica, se produjo el incidente técnico más significativo de esta etapa: el driver

TB6612FNG suministrado por el laboratorio presentó una falla en el circuito integrado durante

un ensayo en la semana 6, dejándolo fuera de funcionamiento. La revisión determinó que el daño

estaba asociado a un defecto de fábrica en el encapsulado del componente. Mateo Tabares Gil

gestionó la adquisición de un reemplazo, y una vez disponible el nuevo driver, se logró integrar

correctamente el segundo motor al sistema de control. Al cierre de la semana 7, el prototipo

realizó sus primeras pruebas de movilidad completa, funcionando de manera adecuada y sin

fallas adicionales.

Paralelamente, Mateo Tabares Gil inició el diseño de la PCB personalizada que centralizaría

todas las conexiones del sistema, tarea cuya duración planeada fue de una semana. En

programación, Juan Sebastián Flórez Molina y el equipo optimizaron el código de control

elaborado en la etapa anterior, bajo una revisión colaborativa que garantizó un mejor desempeño

del sistema.

### 3.3 Semanas 8 y 9: pruebas electrónicas, detección de obstáculos e inicio de visión QR

En la semana 8, Kevin Andrés Chala González asumió las pruebas electrónicas integrales del

vehículo, verificando el correcto funcionamiento de los subsistemas ensamblados. Federico

Gómez Lotero, por su parte, inició la implementación del sistema de detección de obstáculos

mediante los sensores ultrasónicos HC-SR04, realizando pruebas de calibración a diferentes

distancias para garantizar la precisión de respuesta. Al cierre de la semana 9, la detección de

obstáculos alcanzó un estado de completitud del 100 % según el registro de bitácoras.

Juan Flórez inició en paralelo el desarrollo del módulo de detección de códigos QR, utilizando la

cámara IMX219 y la librería OpenCV sobre la Raspberry Pi 5. Las primeras pruebas

evidenciaron errores de decodificación asociados a las condiciones de iluminación del entorno,

lo que llevó al equipo a ajustar los parámetros de detección y a priorizar este desarrollo en la

semana siguiente. En esta misma semana se tomó la decisión de suspender temporalmente las

pruebas electrónicas generales para enfocar los recursos en la optimización del módulo QR,

decisión que reflejó la capacidad del equipo para priorizar según el estado real del proyecto.

### 3.4 Semanas 10 y 11: consolidación del sistema de detección QR

Las semanas 10 y 11 estuvieron centradas en la finalización y optimización del módulo de visión

para detección y decodificación de códigos QR. Juan Flórez y Kevin Chala trabajaron en el

ajuste de los parámetros del algoritmo, la mejora de las condiciones de iluminación sobre la pista

y la calibración del sistema de cámara. Como resultado, la detección QR alcanzó el estado de

finalizada al término de la semana 11, con una tasa de lectura exitosa del 70 % bajo condiciones

de alto contraste, cumpliendo exactamente la meta mínima establecida en los indicadores de

desempeño. El consultor Carlos Rodríguez brindó asesoría técnica durante este proceso,

especialmente en el uso avanzado de la cámara. Simultáneamente, se realizaron las primeras

pruebas de velocidad del vehículo completo, cuyos resultados preliminares mostraron

variabilidad en los tiempos de respuesta, lo que motivó una fase posterior de optimización del

código de control.

### 3.5 Semanas 12 a 15: validación, posicionamiento y documentación

Entre las semanas 12 y 15, el equipo avanzó en la fase de validación del sistema integrado. Las

actividades centrales fueron: las pruebas formales de velocidad, la validación del sistema de

posicionamiento para carga y descarga en las tres estaciones, y la elaboración del manual de

usuario del sistema. Las pruebas de posicionamiento evaluaron la precisión del robot al detener

su movimiento en las coordenadas correctas para ejecutar las operaciones de carga y descarga,

verificando que estas se realizaran de forma segura y sin colisiones. Los resultados confirmaron

la funcionalidad del algoritmo de navegación combinado, que integra la segmentación de línea

para desplazamiento continuo y la decodificación QR para instrucciones en estaciones

específicas.

En cuanto a la gestión del proyecto, estas semanas representaron también una fase de

consolidación documental, en la que el equipo estructuró los reportes de resultados y revisó la

coherencia de la información registrada en las bitácoras de seguimiento a lo largo del semestre.

### 3.6 Semanas 16 y 17: ajustes finales y cierre del proyecto

Las últimas dos semanas del proyecto se destinaron a los ajustes finales de calibración y

posicionamiento del sistema, la realización de las pruebas de entrega funcional y la

consolidación de la documentación técnica y académica. El robot completó de forma autónoma

el ciclo logístico completo, recolectando la carga en la estación de origen y distribuyéndola hacia

las tres estaciones de destino sin intervención humana. La Tabla 1 sintetiza los indicadores clave

de desempeño planificados y los resultados reales obtenidos al cierre del proyecto.

Tabla 1

Indicadores clave de desempeño: metas planeadas y resultados reales

Indicador | Meta planeada | Resultado real
Velocidad en línea recta | ≥ 1,5 km/h | 1,8 km/h
Velocidad en curva | ≥ 1,0 km/h | 1,1 km/h
Torque del sistema de tracción | ≥ 0,5 N/m | 0,73 N/m
Tasa de detección QR (alto contraste) | ≥ 70 % | 70 %
Detección de obstáculos | 100 % | 100 %
Ciclo logístico autónomo completo | 100 % sin intervención | Completado
Carga útil transportada | 1 kg | 1 kg
Nota. Todos los indicadores de desempeño fueron cumplidos al cierre del proyecto.

La Tabla 2 presenta la comparación entre el cronograma planeado y el ejecutado, evidenciando

las dos desviaciones que extendieron la duración del proyecto de 16 a 18 semanas.

Tabla 2

Comparación entre cronograma planeado y ejecutado

Fase / Tarea | Sem. planeadas | Sem. reales | Observación
Acta de constitución | 3 | 3 | Sin desviación
Ensayo de motores | 1 | 3 | Falla en driver TB6612FNG
Diseño mecánico | 2 | 2 | Sin desviación
Ensamble del vehículo | 1 | 2 | Rediseño de soporte de ruedas locas
Diseño PCB / Arranque inicial | 2 | 2 | Sin desviación
Detección de obstáculos | 2 | 2 | Sin desviación
Detección QR | 3 | 3 | Sin desviación
Posicionamiento carga/descarga | 2 | 2 | Sin desviación
Entrega funcional | 1 | 1 | Sin desviación
TOTAL | 16 | 18 | +2 semanas de desviación total
Nota. Fuente: elaboración propia a partir de las bitácoras de seguimiento del proyecto.

El análisis del proceso iterativo documentado en las bitácoras revela tres lecciones transversales

que merecen ser destacadas. En primer lugar, la asesoría técnica oportuna de los directores del

proyecto resultó determinante para resolver los imprevistos técnicos de mayor impacto: la

identificación del cableado incorrecto en los motores y la corrección del sistema de anclaje de las

ruedas locas fueron posibles gracias a la intervención directa de los asesores en momentos clave

del desarrollo. En segundo lugar, la adopción de un sistema de control de versiones en GitHub

para el código y los archivos de diseño CAD permitió al equipo gestionar los rediseños sin

pérdida de información y con trazabilidad completa de los cambios. En tercer lugar, la decisión

de suspender temporalmente las pruebas electrónicas en la semana 9 para priorizar el módulo QR

evidencia una capacidad de gestión adaptativa que contribuyó a mantener el proyecto dentro de

un rango de desviación manejable.

Desde la perspectiva del aprendizaje en ingeniería, el proyecto C.A.L.V.O.S. confirma los

hallazgos de Gallardo Gómez (2017) y Martínez Martínez (2022) respecto a la viabilidad de

sistemas robóticos académicos de bajo costo sobre plataformas embebidas comerciales. La

diferencia principal radica en la integración del ciclo logístico completo, que incluye detección

de destino por QR, desplazamiento autónomo, posicionamiento preciso y operaciones de carga y

descarga, lo que representa un nivel de complejidad sistémica superior al de los trabajos de

referencia.

### 4. Conclusiones

El proceso de desarrollo del robot C.A.L.V.O.S. documentado en este artículo demuestra que un

equipo de cuatro estudiantes de ingeniería puede diseñar, construir y validar un AGV funcional

dentro de un semestre académico, utilizando exclusivamente componentes comerciales de bajo

costo y herramientas de software de código abierto, siempre que cuente con una planificación

estructurada, asesoría técnica oportuna y un sistema riguroso de seguimiento mediante bitácoras.

Los dos imprevistos técnicos que generaron la desviación de dos semanas en el cronograma, la

falla del driver TB6612FNG y el rediseño de los soportes de ruedas, fueron resueltos sin

comprometer el cumplimiento de los objetivos del proyecto. Esta capacidad de respuesta

adaptativa representa en sí misma un resultado valioso del proceso formativo, comparable con la

gestión de riesgos descrita por el Project Management Institute (2021) para proyectos

tecnológicos.

La arquitectura de navegación dual, que combina seguimiento de línea por segmentación de

color con decodificación QR en tiempo real, demostró ser una solución robusta y

económicamente viable para entornos industriales controlados. Como trabajo futuro, se recomienda la exploración de algoritmos SLAM para extender la operabilidad del sistema a

entornos no estructurados, así como la incorporación de protecciones eléctricas adicionales en el

diseño de la PCB para prevenir fallas por errores de conexión durante el mantenimiento.

Agradecimientos

Expresamos nuestro más sincero agradecimiento a todas las personas que hicieron posible el

desarrollo del proyecto C.A.L.V.O.S. (Control Autónomo Logístico Vehicular Optimizado de

Suministros).

En primer lugar, agradecemos a nuestros docentes y asesores académicos por el

acompañamiento, orientación y conocimientos brindados durante cada una de las etapas del

proyecto, contribuyendo significativamente al desarrollo técnico y académico del sistema.

Asimismo, agradecemos a la institución educativa por proporcionar los recursos, espacios y

herramientas necesarias para la ejecución de las pruebas, implementación del prototipo y

desarrollo de las actividades correspondientes.

Finalmente, agradecemos a nuestros compañeros y colaboradores por su compromiso, dedicación

y trabajo en equipo, fundamentales para el cumplimiento de los objetivos planteados y la

culminación satisfactoria del proyecto.

Referencias

Amaguaña Moreta, E. B., Pilapanta Carrasco, K. E., Laica Tulmo, B. F., & Ñacato Estrella, D. R.

(2023). Robots móviles omnidireccionales. Revista Científica Arbitrada Multidisciplinaria

Pentaciencias, 5(2), 36-47.

Gallardo Gómez, L. (2017). Aplicación de visión por computador y machine learning al guiado

de un robot móvil basado en Raspberry Pi [Trabajo de Fin de Grado]. Universidad de Sevilla,

Escuela Técnica Superior de Ingeniería. https://hdl.handle.net/11441/93797

Gallardo Gómez, L. (2017). Desarrollo de un robot de fútbol con detección de pelotas mediante

visión artificial [Trabajo de Fin de Grado]. Universidad de Sevilla, Escuela Técnica Superior de

Ingeniería.

Gómez Patiño, D. A. (2019). Diseño e implementación de un robot móvil autónomo para el

transporte | de | materiales. | Universidad | Tecnológica | de | Pereira.

https://repositorio.utp.edu.co/server/api/core/bitstreams/bc866e76-6744-481c-98da-f63a372768e

8/content

Martínez Martínez, A. (2022). Construcción de un coche de conducción autónomo robótico

[Trabajo | de | Fin | de | Grado]. | Universidad | Politécnica | de | València.

https://riunet.upv.es/server/api/core/bitstreams/acd784a3-e58b-4a2b-9d75-19af5a1b5109/content

OpenCV. (2023). Open source computer vision library [Software]. https://opencv.org

Project Management Institute. (2021). Guía de los fundamentos para la dirección de proyectos

(Guía del PMBOK®) (7.ª ed.). Project Management Institute.

Sapag Chain, N., & Sapag Chain, R. (2014). Preparación y evaluación de proyectos (6.ª ed.).

McGraw-Hill Educación.

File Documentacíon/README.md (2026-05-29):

**Contenido de la Carpeta**

Esta carpeta contiene toda la documentación técnica, administrativa y académica desarrollada durante la ejecución del proyecto integrador del vehículo autónomo. Aquí se almacenan los archivos relacionados con la planeación, seguimiento, desarrollo, validación y presentación final del sistema, permitiendo mantener un control organizado de la información generada a lo largo del semestre.

**Acta de Constitución**

Documento oficial que formaliza el inicio del proyecto. En este archivo se definen los objetivos generales y específicos, el alcance del sistema, la problemática a resolver, la metodología de trabajo, los recursos disponibles y la distribución de roles dentro del equipo de desarrollo. Además, incluye las aprobaciones correspondientes por parte de docentes y asesores encargados del seguimiento del proyecto.

**Bitácoras**

Registro cronológico y detallado del avance semanal del proyecto. Cada bitácora documenta las actividades realizadas durante las sesiones de trabajo, las modificaciones implementadas tanto en hardware como en software, las pruebas ejecutadas, los inconvenientes encontrados y las soluciones aplicadas. También se incluyen observaciones técnicas, acuerdos del equipo y compromisos establecidos para las siguientes fases del desarrollo.

**Informes**

Carpeta destinada al almacenamiento de informes de avance e informe final del proyecto. En estos documentos se describe el desarrollo técnico y metodológico del vehículo autónomo, incluyendo el diseño mecánico, electrónico y de programación. Asimismo, se presentan análisis de resultados, validaciones realizadas, conclusiones obtenidas y recomendaciones para futuras mejoras del sistema.

**Manual de Usuario**

Guía de operación diseñada para facilitar el uso correcto del vehículo autónomo. Este manual explica paso a paso el procedimiento de encendido, configuración inicial, conexión de componentes, ejecución del sistema autónomo y monitoreo del funcionamiento general. También contiene instrucciones para la calibración de sensores, solución de problemas comunes, recomendaciones de seguridad y mantenimiento preventivo del robot.

**Presentaciones**

Contiene las diapositivas utilizadas durante las exposiciones y sustentaciones académicas del proyecto. Estas presentaciones resumen de forma visual y técnica los avances realizados, la arquitectura del sistema, el funcionamiento del vehículo autónomo, las pruebas efectuadas y los resultados obtenidos durante el desarrollo del proyecto integrador.

**Artículo Publicable**

Documento redactado bajo formato académico con el propósito de presentar de manera formal el desarrollo del proyecto. Incluye introducción, planteamiento del problema, metodología implementada, resultados experimentales, análisis técnico y conclusiones finales. Este archivo está orientado a la divulgación académica y puede ser utilizado como base para publicaciones o eventos institucionales.

**Matriz de Control de Documentos**

Archivo utilizado para llevar el control y seguimiento de todos los documentos generados durante el proyecto. En esta matriz se registra información como nombre del documento, versión, fecha de modificación, responsable, estado de aprobación y observaciones correspondientes, garantizando una adecuada gestión documental.

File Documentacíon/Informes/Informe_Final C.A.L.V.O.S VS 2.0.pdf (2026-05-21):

INFORME FINAL — C.A.L.V.O.S. | Página 1

Desarrollo de un Prototipo de un Robot Móvil Autónomo Capaz de Definir

Trayectorias de Transporte de Materiales

Mateo Tabares Gil, Federico Gómez Lotero, Juan Sebastián Flórez Molina,

Kevin Andrés Chala González

Facultad de Tecnología, Programa de Ingeniería Mecatrónica

Universidad Tecnológica de Pereira

Director: Osiel Arbeláez Salazar

Asesores: Angie Tatiana Rengifo Oviedo, Carlos Andrés Rodríguez Pérez,

Edward Andrés González Ríos

Junio de 2026

Resumen

El presente informe final documenta el desarrollo completo del proyecto C.A.L.V.O.S.

(Control Autónomo Logístico Vehicular Optimizado de Suministros), un robot móvil autónomo

diseñado para ejecutar ciclos logísticos de transporte de materiales en entornos industriales

controlados mediante visión artificial, tracción diferencial y códigos QR. El proyecto fue

desarrollado por estudiantes del Programa de Ingeniería Mecatrónica de la Universidad

Tecnológica de Pereira durante un período de 18 semanas. El informe presenta una comparación

entre lo planeado y lo ejecutado en términos de cronograma y presupuesto, los resultados

técnicos obtenidos en las pruebas de funcionamiento, las conclusiones derivadas del proceso y un

conjunto de recomendaciones orientadas a versiones futuras del sistema. El robot logró ejecutar

de forma autónoma el ciclo completo de recolección y distribución de una carga de 1 kg hacia

tres estaciones de destino predefinidas, validando la viabilidad técnica del sistema propuesto.

Palabras clave: robot móvil autónomo, visión artificial, códigos QR, AGV, logística industrial,

navegación autónoma.

Introducción

En el contexto actual de la automatización industrial, la implementación de sistemas

robóticos autónomos se ha convertido en una solución estratégica para optimizar procesos,

mejorar la eficiencia operativa y reducir la intervención humana en tareas repetitivas o de alto

riesgo. La integración de tecnologías como la visión artificial y los sistemas de identificación

mediante códigos QR ha permitido desarrollar mecanismos de guiado más precisos y adaptables

a entornos controlados.

El presente documento constituye el informe final del proyecto C.A.L.V.O.S., cuyo

propósito fue diseñar y desarrollar un robot móvil autónomo capaz de realizar seguimiento de

trayectoria mediante la lectura y procesamiento de códigos QR en entornos industriales

controlados. El sistema integra tecnologías de visión artificial y control de movimiento para

permitir la navegación autónoma y la ejecución eficiente de tareas de transporte dentro de

bodegas.

A lo largo del documento se presenta la comparación entre la planificación inicial y la

ejecución real del proyecto, los resultados obtenidos en las pruebas de funcionamiento, las

conclusiones del equipo de desarrollo y las recomendaciones para el mejoramiento del sistema

en versiones futuras.

Propósito

El propósito del presente proyecto es diseñar e implementar un robot móvil autónomo

capaz de realizar tareas de transporte de materiales dentro de entornos industriales controlados,

utilizando tracción diferencial, tecnologías de visión artificial y navegación mediante códigos

QR. El sistema busca ejecutar de manera autónoma procesos de desplazamiento, carga y

descarga entre estaciones previamente definidas, contribuyendo a la optimización de procesos

logísticos y reducción de la intervención humana en tareas repetitivas.

Adicionalmente, el proyecto tiene como finalidad integrar conocimientos

multidisciplinarios en áreas como robótica, electrónica, programación y automatización,

promoviendo el desarrollo de soluciones tecnológicas aplicadas al sector industrial.

Justificación

La creciente necesidad de mejorar la eficiencia y optimizar los procesos logísticos en

entornos industriales ha impulsado el desarrollo de sistemas automatizados capaces de reducir

tiempos de operación y minimizar la intervención humana en actividades repetitivas. En muchos

casos, las labores de transporte interno dentro de bodegas y plantas de producción continúan

realizándose de manera manual, lo que puede generar disminución en la productividad y

afectaciones ergonómicas en los trabajadores.

En este contexto, el desarrollo de un robot móvil autónomo basado en visión artificial y

navegación mediante códigos QR representa una alternativa tecnológica viable, de bajo costo y

adaptable a entornos controlados. La implementación de este tipo de sistemas permite mejorar la

precisión en el desplazamiento, optimizar el transporte de materiales y fortalecer los procesos de

automatización industrial.

Desde el ámbito académico, el proyecto favorece la aplicación práctica de conocimientos

en electrónica, control automático, programación y sistemas embebidos, fortaleciendo

competencias técnicas y promoviendo el desarrollo de soluciones innovadoras orientadas a la

industria y la automatización.

Objetivos

Objetivo General

Crear un robot móvil autónomo capaz de realizar seguimiento de trayectoria mediante la

detección y procesamiento de códigos QR utilizando visión artificial, para su aplicación en

entornos industriales controlados, en un período de ejecución de 16 semanas.

Objetivos Específicos

- Diseñar la estructura mecánica y el sistema de tracción del robot móvil, garantizando

estabilidad y maniobrabilidad en superficies planas.

- Implementar un sistema de visión artificial capaz de detectar y decodificar códigos QR en

tiempo real.

- Desarrollar el algoritmo de control de movimiento que permita al robot interpretar la

información de los códigos QR y ejecutar desplazamientos precisos.

- Integrar los componentes electrónicos y de programación en un sistema funcional que

permita la navegación autónoma en un entorno controlado.

- Validar el desempeño del prototipo mediante pruebas experimentales que evalúen

precisión de trayectoria, tiempo de respuesta y estabilidad del sistema.

Cronograma: Planeado vs. Real

El proyecto fue planeado originalmente para ejecutarse en 16 semanas. Sin embargo,

durante el desarrollo se presentaron imprevistos técnicos que extendieron la duración total a 18

semanas. A continuación se presenta la comparación entre el cronograma planeado y el

ejecutado.

Tabla 1

Comparación entre el cronograma planeado y el real

Tarea | Semanas planeadas | Semanas reales | Observación
Acta de Constitución | 3 | 3 | Sin desviación
Ensayo de Motores | 1 | 3 | Retraso por falla en driver TB6612
Diseño Mecánico | 2 | 2 | Sin desviación
Ensamble del Vehículo | 1 | 2 | Retraso por rediseño de soporte de balineras
Diseño PCB | 1 | 1 | Sin desviación
Arranque inicial | 1 | 1 | Sin desviación
Detección de Obstáculos | 2 | 2 | Sin desviación.
Detección de QR | 3 | 3 | Sin desviación.
Posicionamiento carga/descarga | 2 | 2 | Sin desviación
Entrega Funcional | 1 | 1 | Sin desviación
TOTAL | 16 semanas | 18 semanas | +2 semana de desviación total

La desviación de dos semanas respecto al cronograma planeado se atribuye

principalmente a dos eventos no previstos: la falla del driver TB 6612 causada por una mala

conexión eléctrica que generó sobrecalentamiento, y el rediseño de los soportes de las ruedas

locas por dimensiones incorrectas que afectaban la estabilidad del vehículo. Ambos imprevistos

fueron identificados, analizados y resueltos durante el desarrollo del proyecto.

Presupuesto: Planeado vs. Real

El presupuesto inicial estimado para el proyecto fue de $86.756.974 COP. Al cierre del

proyecto, el gasto total ejecutado ascendió a $86.906.974 COP, lo que representa una desviación

de $150.000 COP. A continuación se presenta el comparativo por rubro.

Tabla 2

Comparación entre el presupuesto planeado y el ejecutado

Rubro | Planeado (COP) | Real (COP) | Desviación
Componentes electrónicos y materiales | $1.304.463 | $1.454.463 | +11.5%
Recursos humanos | $81.280.000 | $81.280.000 | 0%
Licencias de software | $2.053.362 | $2.053.362 | 0%
Recursos físicos institucionales | $1.038.626 | $1.038.626 | 0%
Recursos físicos propios del equipo | $108.052 | $108.0523 | 0%
TOTAL | $86.756.974 | $86.906.974 | < 1%

La principal causa de desviación presupuestal fue el incremento en los componentes

electrónicos debido a los múltiples daños que hubo en estos.

Resultados

Resultados Mecánicos

La estructura del robot fue diseñada en Fusion 360 e impresa en PLA con la impresora

Anycubic Kobra 3 Combo de primera mano, pero debido a complicaciones se cambió a madera

de corte. Las dimensiones finales del vehículo son 240 mm de largo, 180 mm de ancho y 150

mm de alto (Todas estas medidas fueron dadas sin tomar en cuenta las ruedas). El chasis integra

satisfactoriamente todos los componentes electrónicos, la batería y el sistema de tracción

diferencial compuesto por dos motores JGY-370 con encoder y dos ruedas omnidireccionales de

apoyo. El torque aproximado del sistema de tracción es de 0.73 N/m, suficiente para transportar

la carga útil de 1 kg especificada en los objetivos.

Durante el proceso se identificaron y corrigieron problemas de dimensionamiento en los

soportes de las ruedas locas, que afectaban la estabilidad del vehículo. Tras el rediseño e

impresión de las piezas corregidas, el robot presentó un desplazamiento estable y controlado

sobre superficies planas.

Resultados Electrónicos

El sistema electrónico integra una Raspberry Pi 5 (8 GB) como unidad de cómputo

principal, un ESP32 como controlador de bajo nivel, el driver de motores TB6612FNG, dos

sensores ultrasónicos HC-SR04 y la cámara IMX219 de 8 MP. Se diseñó y fabricó una PCB

personalizada denominada C.A.L.V.O.S. que centraliza las conexiones entre los componentes,

reduciendo el uso de protoboard y mejorando la confiabilidad del sistema.

Durante el proceso de integración electrónica se presentó la falla del driver TB6612 por

sobrecalentamiento, causada por una conexión eléctrica incorrecta. El problema fue identificado,

el componente fue reemplazado y se implementaron buenas prácticas de conexión como

verificación de polaridad y organización del cableado. Adicionalmente, los cables de

alimentación fueron sustituidos por conductores de mayor calibre adecuados a la corriente del

sistema.

Resultados de Programación y Visión Artificial

El sistema de visión artificial fue implementado en Python utilizando la librería OpenCV

sobre la Raspberry Pi 5. La cámara IMX219 captura imágenes en tiempo real que son procesadas

para detectar y decodificar los códigos QR distribuidos en la pista. Los resultados de las pruebas

evidenciaron que la efectividad de lectura QR varía significativamente según el contraste del

código.

La navegación del robot se basa en la segmentación de color con OpenCV para

identificar las líneas de demarcación de la pista, complementada con la decodificación QR para

las instrucciones de ruta en estaciones específicas.

Indicadores Clave de Desempeño (KPIs)

Tabla 3

Resultados de los indicadores clave de desempeño del robot C.A.L.V.O.S.

Indicador | Meta planeada | Resultado real | Estado
Velocidad en línea recta | ≥ 1.5 km/h | 1.8 km/h | ✔ Cumplido
Velocidad en curva | ≥ 1.0 km/h | 1.1 km/h | ✔ Cumplido
Torque del sistema de tracción | ≥ 0.5 N/m | 0.73 N/m | ✔ Cumplido
Tasa de detección QR (alto contraste) | ≥ 70% | 70% | ✔ Cumplido
Detección de obstáculos | 100% | 100% | ✔ Cumplido
Ciclo logístico autónomo completo | 100% sin intervención | Completado | ✔ Cumplido
Carga útil transportada | 1 kg | 1 kg | ✔ Cumplido

El robot logró completar de forma autónoma el ciclo logístico completo, recolectando y

distribuyendo una carga de 1 kg hacia las tres estaciones de destino sin intervención humana,

cumpliendo el objetivo principal del proyecto.

Cambio de artículo

Debido a que la revista propuesta inicialmente para la publicación del artículo no cuenta

actualmente con una certificación vigente, se decidió realizar un cambio hacia la revista RIDI

(Revista de Investigación, Desarrollo e Innovación). Esta decisión se tomó considerando que dicha revista posee una certificación vigente y, adicionalmente, presenta una mayor afinidad

temática con el estudio y los objetivos planteados en el presente documento.

Conclusiones

El robot C.A.L.V.O.S. ejecutó exitosamente el ciclo logístico completo, recolectando y

distribuyendo una carga de 1 kg hacia las tres estaciones de destino sin intervención humana,

validando la efectividad del sistema de navegación por códigos QR en entornos controlados.

El uso exclusivo de componentes comerciales y software de código abierto demostró que

es posible desarrollar un AGV funcional y de bajo costo dentro del marco académico,

comprobando la viabilidad técnica y económica de este tipo de soluciones para la automatización

logística.

El proyecto demostró que la integración de visión artificial, navegación autónoma y

manipulación de carga en un único sistema robótico representa una solución práctica y relevante

frente a la creciente demanda de automatización en procesos logísticos industriales.

El diseño mecánico y el sistema de tracción diferencial garantizaron la estabilidad y

maniobrabilidad del robot en superficies planas, logrando velocidades de 1.8 km/h en línea recta

y 1.1 km/h en curva, con un torque de 0.73 N/m suficiente para la carga útil especificada.

La desviación de una semana en el cronograma y del 19.1% en el presupuesto, aunque

significativa, estuvo asociada a imprevistos técnicos que fueron identificados, documentados y resueltos de manera efectiva por el equipo, fortaleciendo las competencias de resolución de

problemas en ingeniería.

Recomendaciones

1. Estandarización del tamaño y posicionamiento de los códigos QR Si bien el sistema

logró una tasa de detección del 90% con códigos de alto contraste, se recomienda definir un

protocolo de instalación que especifique la altura de montaje, el ángulo de inclinación respecto a

la cámara y la distancia mínima entre códigos consecutivos. Esto permitiría reducir los errores de

lectura asociados a la posición del robot al momento de la detección y mejorar la consistencia del

sistema en futuras versiones.

2. Optimización del diseño de la PCB para versiones futuras. La PCB fue fabricada

exitosamente por una empresa especializada, lo que mejoró significativamente la confiabilidad

del sistema respecto al montaje inicial en protoboard. Para la siguiente versión se recomienda

revisar el diseño incorporando protecciones adicionales como fusibles de superficie, diodos de

protección contra inversión de polaridad y pistas de mayor sección transversal en los circuitos de

potencia, con el fin de prevenir daños en componentes críticos como el driver TB6612 ante

eventuales errores de conexión durante el mantenimiento.

3. Protocolo de verificación eléctrica antes del ensamble Dado que la falla del driver por

mala conexión representó la mayor desviación del cronograma, se recomienda implementar un

protocolo formal de verificación eléctrica antes de energizar cualquier subsistema: comprobación

de polaridad, medición de resistencia entre pines y revisión del calibre de los cables según la

corriente nominal de cada componente.

4. Reserva de contingencia en el presupuesto de materiales Aunque la desviación total del

presupuesto fue inferior al 1%, los daños en componentes electrónicos generaron costos adicionales no previstos. Se recomienda incluir en futuros proyectos similares una reserva de

contingencia del 15% sobre el rubro de componentes electrónicos, destinada exclusivamente a

reposición de piezas dañadas durante pruebas e integración.

5. Escalabilidad hacia entornos menos estructurados El sistema actual opera

correctamente en superficies planas con iluminación estable y códigos QR en posiciones fijas.

Para versiones futuras se recomienda explorar la integración de un algoritmo SLAM

(Simultaneous Localization and Mapping) que permita al robot construir un mapa del entorno en

tiempo real, ampliando su operabilidad a espacios menos estructurados y haciéndolo más

competitivo para aplicaciones industriales reales.

Anexos

F. Gómez Lotero, "Grupo-4-direccional- / Mecánica," GitHub, 2026. [Online]. Available:

https://github.com/kchala12/Grupo-4-direccional-/tree/main/Mecanica

J. S. Flórez Molina, "Grupo-4-direccional- / src," GitHub, 2026. [Online]. Available:

https://github.com/kchala12/Grupo-4-direccional-/tree/main/src

M. Tabares Gil, "Grupo-4-direccional- / Electrónica," GitHub, 2026. [Online]. Available:

https://github.com/kchala12/Grupo-4-direccional-/tree/main/Electronica

K. A. Chala González, "Grupo-4-direccional- / Documentación," GitHub, 2026. [Online].

Available: https://github.com/kchala12/Grupo-4-direccional-/tree/main/Documentaci%C3%B3n

Referencias

Amaguaña Moreta, E. B., Pilapanta Carrasco, K. E., Laica Tulmo, B. F., & Ñacato Estrella, D. R.

(2023). | Robots | móviles | omnidireccionales. | Revista | Científica | Arbitrada

Multidisciplinaria Pentaciencias, 5(2), 36–47.

Baca Urbina, G. (2016). Evaluación de proyectos (7.ª ed.). McGraw-Hill Educación.

Departamento Nacional de Planeación. (2019). Guía metodológica para la formulación de

proyectos de inversión pública. DNP.

Echeverri, G. (2018). Formulación y evaluación de proyectos. Ecoe Ediciones.

Ferreira Neto, N. A. (2022). Visual-based perception for autonomous vehicles in off-road

environment using deep learning. Programa de Pós-Graduação em Engenharia Elétrica.

https://arxiv.org/pdf/2509.19378

Gallardo Gómez, L. (2017). Aplicación de visión por computador y machine learning al guiado

de un robot móvil basado en Raspberry Pi [Trabajo de Fin de Grado]. Universidad de

Sevilla, Escuela Técnica Superior de Ingeniería. https://hdl.handle.net/11441/93797

Gallardo Gómez, L. (2017). Desarrollo de un robot de fútbol con detección de pelotas mediante

visión artificial [Trabajo de Fin de Grado]. Universidad de Sevilla, Escuela Técnica

Superior de Ingeniería.

Gómez Patiño, D. A. (2019). Diseño e implementación de un robot móvil autónomo para el

transporte | de | materiales. | Universidad | Tecnológica | de | Pereira.

https://repositorio.utp.edu.co/server/api/core/bitstreams/bc866e76-6744-481c-98da-f63a3

72768e8/content

Martínez Martínez, A. (2022). Construcción de un coche de conducción autónomo robótico

[Trabajo | de | Fin | de | Grado]. | Universidad | Politécnica | de | València.

https://riunet.upv.es/server/api/core/bitstreams/acd784a3-e58b-4a2b-9d75-19af5a1b5109/

content

OpenCV. (2023). Open source computer vision library [Software]. https://opencv.org

Project Management Institute. (2021). Guía de los fundamentos para la dirección de proyectos

(Guía del PMBOK®) (7.ª ed.). Project Management Institute.

Sapag Chain, N., & Sapag Chain, R. (2014). Preparación y evaluación de proyectos (6.ª ed.).

McGraw-Hill Educación.

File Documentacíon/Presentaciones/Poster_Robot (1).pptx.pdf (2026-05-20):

### Universidad Tecnológica de Pereira

Facultad de Tecnología · Ingeniería Mecatrónica

# Control Autonomo Logistico Vehicular Optimizado de Suministros (C.A.L.V.O.S)

Mateo Tabares Gil · Federico Gómez Lotero · Juan Sebastián Flórez Molina · Kevin Andrés Chala González

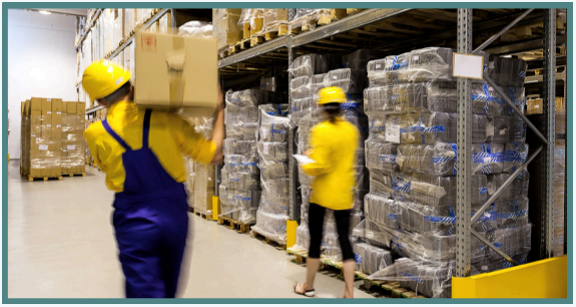
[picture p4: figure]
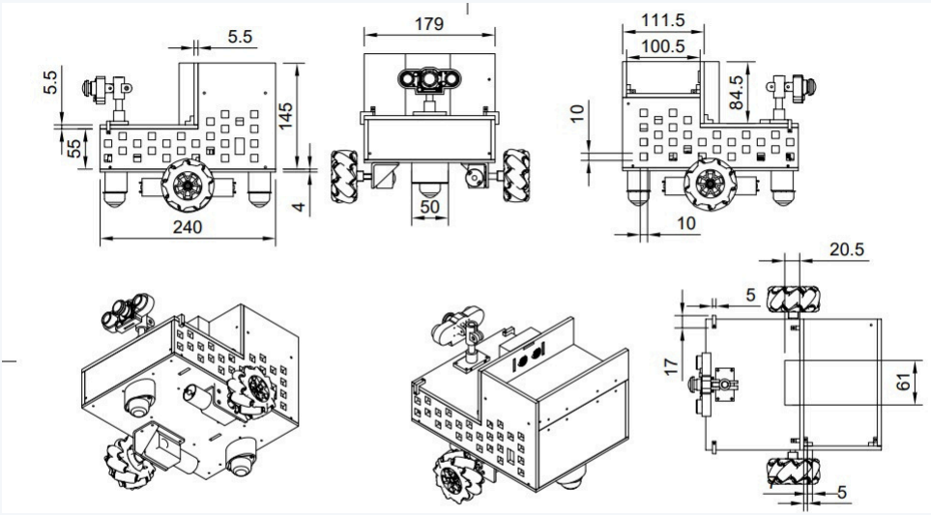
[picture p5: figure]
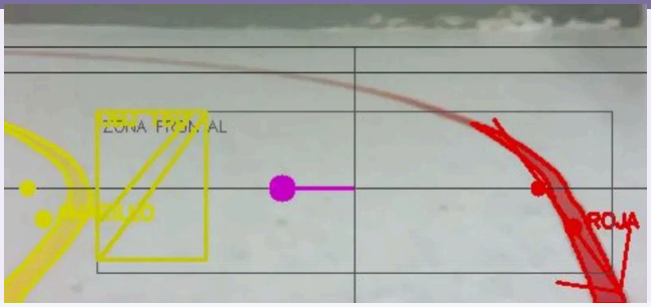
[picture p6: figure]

### Universidad Tecnológica de Pereira · Facultad de Tecnología · Ingeniería Mecatrónica Pereira, Colombia · 2026

Resumen

Planteamiento del Problema y Justificación

Problema:

Tecnológicas

Falta de herramientas
asequibles

Monetarias
Alternativas de
muy alto precio

Mercado

No existen
empresas dedicadas
a este mercado

Normativas

Poca capacitación
técnica disponible
Justificación:

Objetivos

Específicos:

### 1 Movimiento efecetivo de una carga de 1 Kg

### 2 Autonomía de cualquier tipo de persona

3

Lectura de Qr y tome decisiones con base a estos

### 4 Diseño de un Robot con tracción Diferencial

Metodología

1

## Recolección de información Obtención de datos relevantes sobre visión artificial y sistemas embebidos

2

## Análisis de la información Evaluación y procesamiento de los datos recolectados para definir la arquitectura del sistema

3

## Diseño de la herramienta Creación de la estructura mecánica, electrónica y arquitectura de software del robot

4

## Construcción del sistema Desarrollo físico del prototipo e integración de todos los componentes electrónicos

5

## Implementación Puesta en marcha y pruebas del sistema integrado en entorno controlado de laboratorio

6

## Divulgación de resultados Compartir y documentar los resultados obtenidos en el proyecto académico

Resultados

Se completaron las etapas metodológicas preliminares del proyecto, obteniendo los siguientes avances:

Diseño mecánico

Estructura del chasis modelada en Fusion con tracción diferencial y ruedas omnidireccionales traseras, lista para impresión 3D en PLA.

Sistema de visión integrado

Módulo de detección de códigos QR implementado con cámara IMX219 y OpenCV sobre Raspberry Pi 5, con lectura en tiempo real.

Electrónica ensamblada
Integración validada de ESP32, puente H TB6612, motores JGY370 con encoder y batería LiPo 5000 mA en protoboard de pruebas.

Algoritmo de navegación

Lógica de seguimiento de trayectoria basada en lectura secuencial de QR con decisiones de giro y avance correctamente implementada.

Conclusiones

### 1 Integración de tecnologías autónomas

El desarrollo del robot móvil autónomo permitió integrar tecnologías de visión artificial y navegación mediante códigos QR para el transporte automatizado de materiales en entornos controlados.

### 2 Viabilidad del sistema

El proyecto demostró que es posible implementar un sistema de transporte autónomo funcional utilizando componentes de bajo costo y herramientas de software de código abierto.

### 3 Fortalecimiento de competencias técnicas

La implementación del prototipo fortaleció conocimientos en programación, electrónica, control y robótica aplicada, cumpliendo con los objetivos planteados dentro del tiempo establecido.

### 4 Proyección y aplicabilidad industrial

Finalmente, el proyecto representa una base para futuras mejoras en automatización y aplicaciones logísticas dentro del ámbito industrial.

Boceto de diseño del Robot Autónomo

El presente proyecto tiene como propósito el diseño y desarrollo de un Vehículo Guiado Autónomo con visión artificial, capaz de realizar un recorrido predefinido a través de tres estaciones, transportando y descargando una carga de hasta 1 kg en puntos específicos.

El sistema integra tecnologías de procesamiento de imágenes mediante códigos QR como guías de navegación, control de movimiento diferencial, simulando su funcionamiento en un entorno industrial controlado.

El proyecto busca consolidar la aplicación práctica de conocimientos multidisciplinarios en electrónica, robótica y automatización, contribuyendo a la optimización de procesos industriales y al fortalecimiento de competencias técnicas en ingeniería.

Actualmente, diversas industrias en Colombia presentan limitaciones en la implementación de sistemas eficientes de transporte logístico automatizado dentro de bodegas, dependiendo en gran medida de labores realizadas por trabajadores. Esta situación puede generar afectaciones ergonómicas y enfermedades musculoesqueléticas, especialmente relacionadas con la espalda, debido a la manipulación y transporte constante de cargas.

La creciente necesidad de mejorar la eficiencia y optimizar los procesos logísticos en entornos industriales ha impulsado el desarrollo de sistemas automatizados capaces de reducir tiempos de operación y minimizar la intervención humana en actividades repetitivas.

General: Diseñar y desarrollar un robot móvil autónomo que permita modelar y gestionar de manera integral el transporte de materiales en entornos industriales controlados, mejorando la toma de decisiones, optimizando procesos operativos y fortaleciendo las competencias técnicas de los usuarios en entornos formativos.

Imagenes de comparación

Referencias Principales

[1] Gallardo Gómez, L. (2017). Desarrollo de un robot de fútbol con detección de pelotas mediante visión artificial. Universidad de Sevilla Escuela Técnica Superior de Ingeniería.
[2] Gallardo Gómez, L. (2017). Aplicación de visión por computador y machine learning al guiado de un robot móvil basado en Raspberry Pi. Universidad de Sevilla, Escuela Técnica Superior de Ingeniería.
[3] Martínez Martínez, A. (2022). Construcción de un coche de conducción autónomo robótico. Universidad Politécnica de València.
[4] Gómez Patiño, D. A. (2019). Diseño e implementación de un robot móvil autónomo para el transporte de materiales. Universidad Tecnológica de Pereira.
[5] Ferreira Neto, N. A. (2022). Visual-based perception for autonomous vehicles in off-road environment using deep learning. Programa de Pós-Graduação em Engenharia Elétrica.

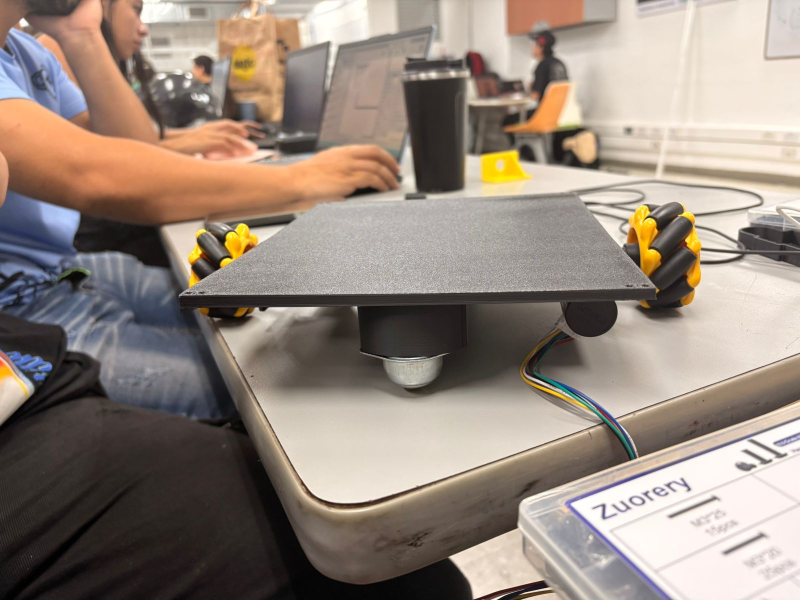
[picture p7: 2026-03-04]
Electronica/Imágenes Electrónica/base.jpeg

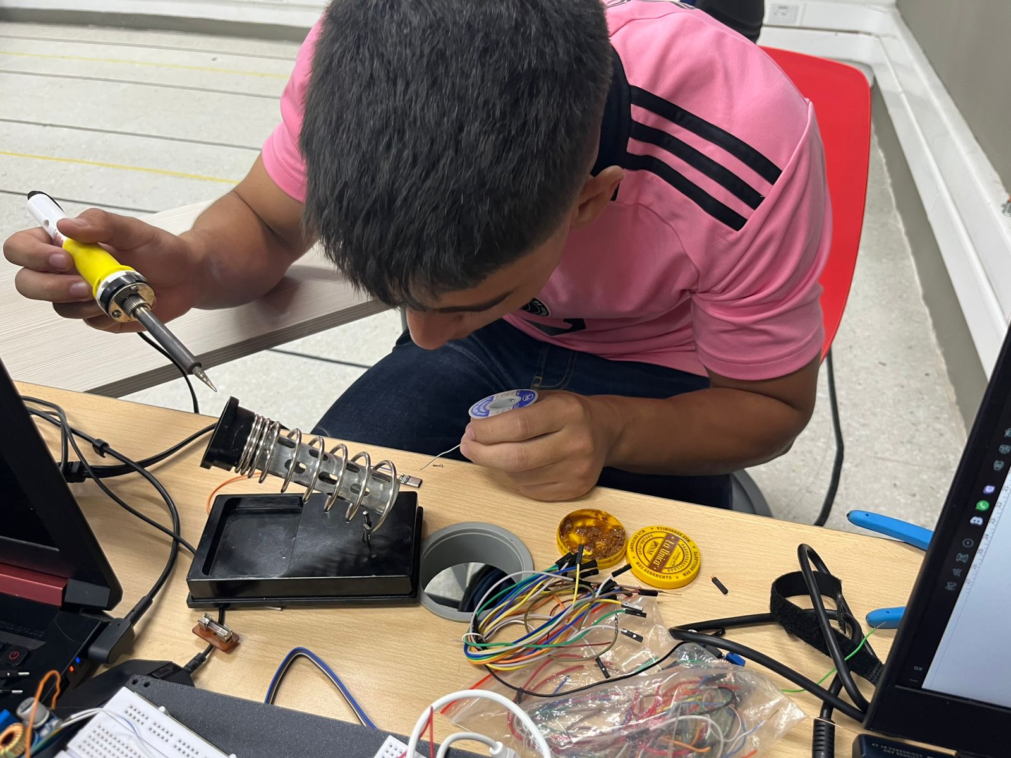
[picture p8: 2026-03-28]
Electronica/Imágenes Electrónica/TABAJO FEDE.jpeg

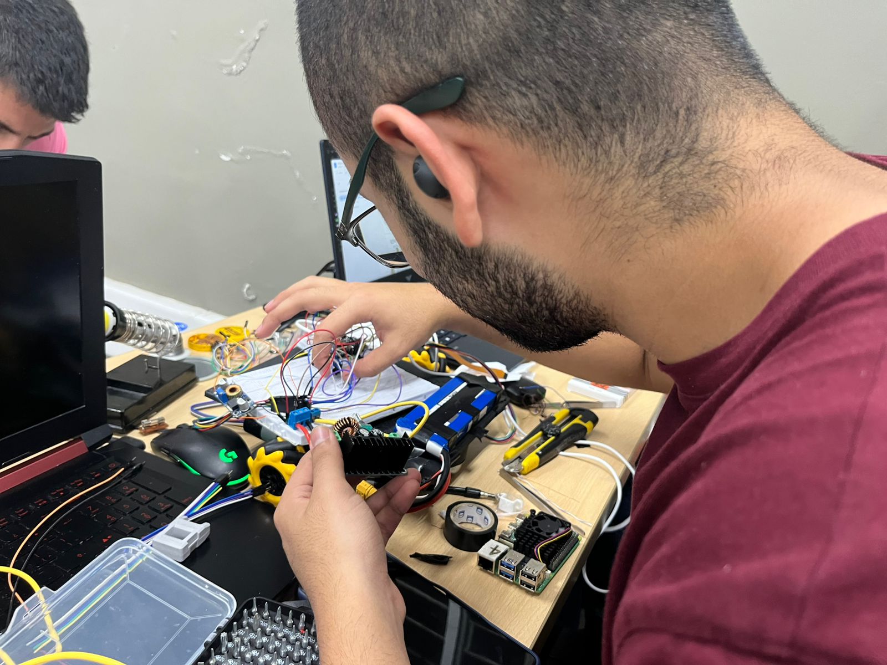
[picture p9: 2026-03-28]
Electronica/Imágenes Electrónica/TRABAJO FLOREZ.jpeg

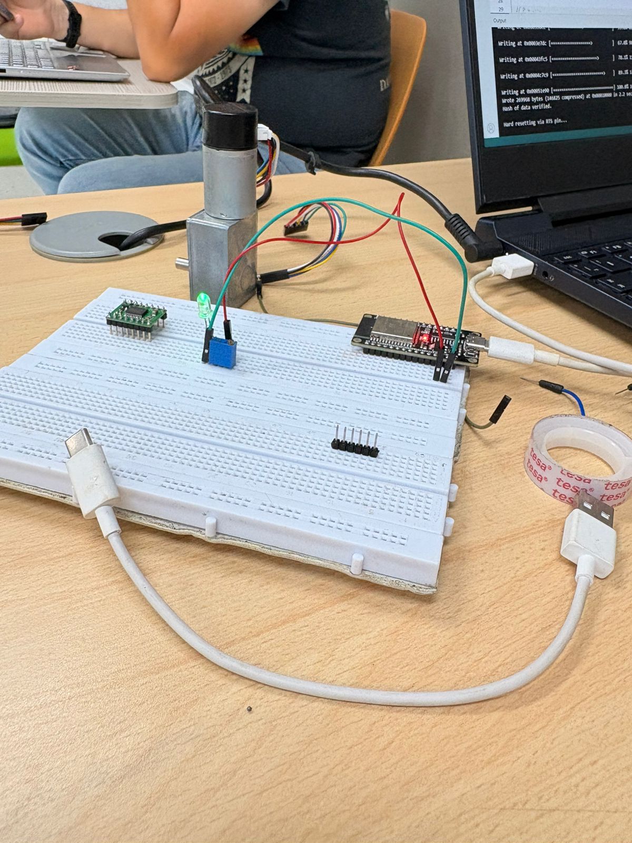
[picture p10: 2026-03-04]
Electronica/Imágenes Electrónica/Electronica.jpeg

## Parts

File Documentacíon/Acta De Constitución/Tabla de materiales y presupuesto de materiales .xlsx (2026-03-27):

Tabla de Materiales
Nombre | Precio | Cantidad | Link | Imágenes | Total sin iva | Valor Total
ESP32 | $26306 | 1 | Tarjeta De Desarrollo Esp Wroom 32 Esp322 Wifi Bluetooth GENERICO | falabella.com (https://www.falabella.com.co/falabella-co/product/129449389/Tarjeta-De-Desarrollo-Esp-Wroom-32-Esp322-Wifi-Bluetooth/129449390) | #VALUE! | $22106 | $26306
Raspberry Pi 5 (8GB) | $491852 | 1 | Raspberry Pi 5 8GB RPI5-8GB-SINGLE CON DISIPADOR (EXT IVA) (https://www.vistronica.com/board-de-desarrollo/raspberry-pi/raspberry-pi-5-8gb-rpi5-8gb-single-con-disipador-ext-iva-detail.html) | #VALUE! | $413321 | $491852
Filamento PLA 1kg | $60000 | 1 | https://ari3d.co/product/filamento-anycubic-pla-negro/ | #VALUE! | $50421 | $60000
PCB | $20000 | 1 | https://www.pcbcart.com/ | #VALUE! | $16807 | $20000
Protoboard | $12000 | 1 | https://dualtronica.com/miscelanea/625-protoboard-generica-mb-102-830-puntos.html | #VALUE! | $10084 | $12000
Jumpers | $8000 | 1 | https://dualtronica.com/cables-y-pines/42-cables-dupont-jumper-macho-macho.html | #VALUE! | $6723 | $8000
Cable UTP | $3000 | 1 | Metro De Cable UTP Categoría 5E, 100% Cobre (https://dualtronica.com/cables-y-pines/256-metro-de-cable-utp-categoria-5e-100-cobre-.html) | #VALUE! | $2521 | $3000
Cámara IMX219 | $245000 | 1 | Módulo Cámara Infrarroja 8mp Imx219-160ir Para Jetson Nano | Cuotas sin interés (https://articulo.mercadolibre.com.co/MCO-928922399-modulo-camara-infrarroja-8mp-imx219-160ir-para-jetson-nano-_JM) | #VALUE! | $205882 | $245000
Motores JGY 370 (2 und) | $69706 | 2 | Motorreductor Jgy370 Con Encoder Y Engranaje Metálico | Cuotas sin interés (https://www.mercadolibre.com.co/dc-24v-gear-motor-jgy370-encoder-reduction-full-metal/p/MCO2027613074) | #VALUE! | $117152 | $139412
Cable Serial USB | $24600 | 1 | Cable Usb A 2.0 A Usb C 1M Con Revestimiento De Aluminio (Negro) (https://www.exito.com/cable-usb-a-20-a-usb-c-1m-con-revestimiento-de-aluminio-negro-103746966-mp/p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) | #VALUE! | $20672 | $24600
Ruedas omnidireccionales (2) | $15000 | 2 | Llanta Omnidireccional 60mm Derecha, para motorreductor amarillo (https://dualtronica.com/llantas-para-robotica/888-llanta-omnidireccional-60mm-derecha-para-motorreductor-amarillo.html) | #VALUE! | $25210 | $30000
Puente H TB 6612 | $13600 | 1 | TB6612FNG Puente H Driver Controlador Motor Dual 1A Arduino GENERICO | falabella.com (https://www.falabella.com.co/falabella-co/product/140481742/tb6612fng-puente-h-driver-controlador-motor-dual-1a-arduino/140481743) | #VALUE! | $11428 | $13600
DC DC XL4005 5 A, Reductor Step Down Buck | $14000 | 2 | https://dualtronica.com/inicio/526-dc-dc-xl4005-5-a-reductor-step-down-buck.html | #VALUE! | $22960 | $28000
Tornillos M3 (22 und) | $29100 | 22(710) | https://www.amazon.com/-/es/dp/B0F3JKMZLN | #VALUE! | $24454 | $29100
Tornillos M4 (4 und) | $3000 | 4(2) | Tornillo Bristol M4-0.7 X20 2 Undidades Fixser - Homecenter.com.co (https://www.homecenter.com.co/homecenter-co/product/593018/tornillo-bristol-m4-07-x20-2-undidades-fixser/593018/) | #VALUE! | $5042 | $6000
Rueda tipo balín | $5000 | 2 | https://dualtronica.com/inicio/385-rueda-loca-metalica-para-robotica.html | #VALUE! | $8403 | $10000
Batería LiPo Turnigy 11.1V 5000mAh | $210000 | 1 | https://demosspro.com/806-bateria-lipo-turnigy-111-v-3s-5000mah-20-30c-xt60.html | #VALUE! | $176471 | $210000
Sensor ultrasonido Hc-sr04 | $8000 | 2 | https://dualtronica.com/sensores/71-sensor-ultrasonido-hc-sr04.html | #VALUE! | $13120 | $16000
Total | $1258164 |  |  |  | $1152777 | $1372870

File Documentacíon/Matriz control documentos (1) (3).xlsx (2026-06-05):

Robot Móvil Autónomo de Tracción Diferencial |  | LISTADO MAESTRO DE DOCUMENTOS
SGC-001
VERSION 01
2025-09-23
Número de Documento | Título del Documento | Versión | Fecha de Emisión/Revisión | Historial de Revisiones (Fecha – Autor – Descripción) | Estado | Autor | Revisor | Aprobador | Ubicación | Control de Acceso | Lista de Distribución | Período de Retención | Método de Eliminación | Referencias | Formato
DOC-001 | Acta de Constitución | 2.0 | 2026-03-06 | 17/02/2026 – Todos – Creación del documento (Versión 1.0, no aprobado por correcciones requeridas) | CONCLUIDO | Integracion Completa | Kevin Chala | Tatiana Rengifo | GIT HUB | Lectura: Tatiana Rengifo Oviedo, Carlos Andres Rodriguez, Edward Andres Gonzalez Rios Escritura: Mateo Tabares, Juan Florez, Federico Gomez y Kevin Chala | Equipo del proyecto | 6 meses | Borrado seguro digital | Plan del Proyecto | WORD
 |  |  |  | 06/03/2026 – Todos – Documento aprobado (Versión 2.0)
DOC-002 | Boceto del automata | 2.0 | 2026-03-07 | 17/02/2026 – Todos – Creación del documento (Versión 1.0, no aprobado por correcciones requeridas) | CONCLUIDO | Federico Gomez | Kevin Chala | Edward Gonzalez | GIT HUB | Libre | Equipo del proyecto | 6 meses | Borrado seguro digital | Plan del Proyecto | CAD
 |  |  |  | 06/03/2026 – Todos – Documento aprobado (Versión 2.0)
DOC-003 | Prueba de motores 1 | 2.0 | 2026-03-08 |  | CONCLUIDO | Juan Florez | Mateo Tabares | Carlos Rodriguez | GIT HUB | Libre | Equipo del proyecto | 6 meses | Borrado seguro digital | Plan del Proyecto | CAD
 |  |  |  | 06/03/2026 – Todos –Juan Sebastian Florez (Versión 1.0, no aprobado por correcciones requeridas)
DOC-004 | Prueba de motores 2 | 2.0 | 2026-03-09 |  | CONCLUIDO | Juan Florez | Mateo Tabares | Carlos Rodriguez | GIT HUB | Libre | Equipo del proyecto | 6 meses | Borrado seguro digital | Plan del Proyecto | CAD
 |  |  |  | 09/03/2026 – Todos –Juan Sebastian Florez (Versión 1.0, no aprobado por correcciones requeridas)
DOC-005 | Prueba de motores 3 | 2.0 | 2026-03-12 |  | CONCLUIDO | Juan Florez | Mateo Tabares | Carlos Rodriguez | GIT HUB | Libre | Equipo del proyecto | 6 meses | Borrado seguro digital | Plan del Proyecto | CAD
 |  |  |  | 12/03/2026 – Todos –Juan Sebastian Florez (Versión 1.0, no aprobado por correcciones requeridas)
DOC-006 | Prueba de motores 4 | 2.0 | 2026-03-12 |  | CONCLUIDO | Juan Florez | Mateo Tabares | Carlos Rodriguez | GIT HUB | Libre | Equipo del proyecto | 6 meses | Borrado seguro digital | Plan del Proyecto | CAD
 |  |  |  | 12/03/2026 – Todos –Juan Sebastian Florez (Versión 1.0, no aprobado por correcciones requeridas)
DOC-007 | Prueba de motores 5 | 2.0 | 2026-03-12 |  | CONCLUIDO | Juan Florez | Mateo Tabares | Carlos Rodriguez | GIT HUB | Libre | Equipo del proyecto | 6 meses | Borrado seguro digital | Plan del Proyecto | CAD
 |  |  |  | 12/03/2026 – Todos –Juan Sebastian Florez (Versión 1.0, no aprobado por correcciones requeridas)
DOC-008 | Prueba de motores 6 | 2.0 | 2026-03-12 |  | CONCLUIDO | Juan Florez | Mateo Tabares | Carlos Rodriguez | GIT HUB | Libre | Equipo del proyecto | 6 meses | Borrado seguro digital | Plan del Proyecto | CAD
 |  |  |  | 12/03/2026 – Todos –Juan Sebastian Florez (Versión 1.0, no aprobado por correcciones requeridas)
DOC-009 | Prueba de motores 7 | 2.0 | 2026-03-12 |  | CONCLUIDO | Juan Florez | Mateo Tabares | Carlos Rodriguez | GIT HUB | Libre | Equipo del proyecto | 6 meses | Borrado seguro digital | Plan del Proyecto | CAD
 |  |  |  | 12/03/2026 – Todos –Juan Sebastian Florez (Versión 1.0, no aprobado por correcciones requeridas)
DOC-010 | Boceto del automata | 2.0 | 2026-03-06 | 06/03/2026 – Todos –Juan Sebastian Florez (Versión 1.0, no aprobado por correcciones requeridas) | CONCLUIDO | Juan Florez | Mateo Tabares | Edward Gonzalez | GIT HUB | Libre | Equipo del proyecto | 6 meses | Borrado seguro digital | Plan del Proyecto | .py
DOC-011 | Cronograma | 2.0 | 2026-03-06 |  | CONCLUIDO | Kevin Chala | Mateo Tabares | Tatiana Rengifo | GIT HUB | Lectura: Tatiana Rengifo Oviedo, Carlos Andres Rodriguez, Edward Andres Gonzalez Rios Escritura: Mateo Tabares, Juan Florez, Federico Gomez y Kevin Chala | Equipo del proyecto | 6 meses | Borrado seguro digital | Plan del Proyecto | EXCEL
 |  |  |  | 06/03/2026 – Todos – Documento aprobado (Versión 1.0)
DOC-012 | Diseño De Acoples de Motor | 2.0 | 2026-03-06 |  | CONCLUIDO | Federico Gomez | Juan Florez | Edward Gonzalez | GIT HUB | Libre | Equipo del proyecto | 6 meses | Borrado seguro digital | Plan del Proyecto | CAD
 |  |  |  | 06/03/2026 (Federico Gomez –Diseño de Automata)
DOC-013 | Diseño De Acoples de Camara | 2.0 | 2026-03-06 |  | CONCLUIDO | Federico Gomez | Juan Florez | Edward Gonzalez | GIT HUB | Libre | Equipo del proyecto | 6 meses | Borrado seguro digital | Plan del Proyecto | CAD
 |  |  |  | 06/03/2026 (Federico Gomez –Diseño de Automata)
DOC-014 | Diseño De Acoples de Ruedas | 2.0 | 2026-03-06 |  | CONCLUIDO | Federico Gomez | Juan Florez | Edward Gonzalez | GIT HUB | Libre | Equipo del proyecto | 6 meses | Borrado seguro digital | Plan del Proyecto | CAD
 |  |  |  | 06/03/2026 (Federico Gomez –Diseño de Automata)
DOC-015 | Dibujo CAD | 2.0 | 2026-03-06 |  | CONCLUIDO | Federico Gomez | Juan Florez | Edward Gonzalez | GIT HUB | Libre | Equipo del proyecto | 6 meses | Borrado seguro digital | Plan del Proyecto | CAD
 |  |  |  | 06/03/2026 (Federico Gomez –Diseño de Automata)
DOC-016 | Diseño De Acoples | 2.0 | 2026-03-06 |  | CONCLUIDO | Federico Gomez | Juan Florez | Edward Gonzalez | GIT HUB | Libre | Equipo del proyecto | 6 meses | Borrado seguro digital | Plan del Proyecto | CAD
 |  |  |  | 06/03/2026 (Federico Gomez –Diseño de Automata)
DOC-017 | Bitácora Semana 4 y 5 | 2.0 | 2026-02-20 | 16/02/2026 (Version 1- Kevin Chala,-Solo planeación) | CONCLUIDO | Kevin Chala | Mateo Tabares | Tatiana Rengifo | GIT HUB | Lectura: Tatiana Rengifo Oviedo, Carlos Andres Rodriguez, Edward Andres Gonzalez Rios Escritura: Mateo Tabares, Juan Florez, Federico Gomez y Kevin Chala | Equipo del proyecto | 6 meses | Borrado seguro digital | Plan del Proyecto | WORD
 |  |  |  | 20/02/2026 ( Version 2- Kevin Chala- Planeación y ejecución)
DOC-018 | Informe semana 5 | 2.0 | 2026-02-20 | 20/02/2026 ( Version 1 - Kevin Chala- Cumulo de Avances) | CONCLUIDO | Kevin Chala | Mateo Tabares | Tatiana Rengifo | GIT HUB | Lectura: Tatiana Rengifo Oviedo, Carlos Andres Rodriguez, Edward Andres Gonzalez Rios Escritura: Mateo Tabares, Juan Florez, Federico Gomez y Kevin Chala | Equipo del proyecto | 6 meses | Borrado seguro digital | Plan del Proyecto | WORD
DOC-019 | Bitácora Semana 6 y 7 | 2.0 | 2026-03-07 | 20/02/2026 (Version 1- Mateo Tabares,-Solo planeación) | CONCLUIDO | Mateo Tabares | Kevin Chala | Tatiana Rengifo | GIT HUB | Lectura: Tatiana Rengifo Oviedo, Carlos Andres Rodriguez, Edward Andres Gonzalez Rios Escritura: Mateo Tabares, Juan Florez, Federico Gomez y Kevin Chala | Equipo del proyecto | 6 meses | Borrado seguro digital | Plan del Proyecto | WORD
 |  |  |  | 07/03/2026 ( Version 2- Kevin Chala- Planeación y ejecución)
DOC-020 | Bitácora Semana 8 y 9 | 2.0 | 2026-04-03 | 07/03/2026 (Version 1- Federico Gomez,-Solo planeación) | CONCLUIDO | Federico Gomez | Kevin Chala | Tatiana Rengifo | GIT HUB | Lectura: Tatiana Rengifo Oviedo, Carlos Andres Rodriguez, Edward Andres Gonzalez Rios Escritura: Mateo Tabares, Juan Florez, Federico Gomez y Kevin Chala | Equipo del proyecto | 6 meses | Borrado seguro digital | Plan del Proyecto | WORD
 |  |  |  | 03/04/2026 ( Version 2- Federico Gomez - Planeación y ejecución)
DOC-021 | Bitácora Semana 10 y 11 | 2.0 | 2026-04-17 | 3/04/2026 (Version 1- Federico Gomez,-Solo planeación) | CONCLUIDO | Federico Gomez | Kevin Chala | Tatiana Rengifo | GIT HUB | Lectura: Tatiana Rengifo Oviedo, Carlos Andres Rodriguez, Edward Andres Gonzalez Rios Escritura: Mateo Tabares, Juan Florez, Federico Gomez y Kevin Chala | Equipo del proyecto | 7 meses | Borrado seguro digital | Plan del Proyecto | WORD
 |  |  |  | 17/04/2026( Version 2- Federico Gomez - Planeación y ejecución)
DOC-021 | Modelo PCB 3D | 2.0 | 2026-04-06 | 31/03/2026 (Version 1 Mateo Tabares Gil) | CONCLUIDO | Mateo Tabares | Todo el equipo | Edward Gonzalez | GIT HUB | Libre | Equipo del proyecto | 6 meses | Borrado seguro digital | Plan del Proyecto | FUSION
 |  |  |  | 6/04/2026 (Version 2- Mateo Tabares Gil)
DOC-022 | Boceto PCB | 2.0 | 2026-03-20 | 20/03/2026 (Version 1 Mateo Tabraes Gil) | CONCLUIDO | Mateo Tabares | Todo el equipo | Edward Gonzalez | GIT HUB | Libre | Equipo del proyecto | 6 meses | Borrado seguro digital | Plan del Proyecto | Imagen
 |  |  |  | 20/03/2026 (Version 2- Mateo Tabares Gil)
DOC-023 | Prueba de motores 8 | 2.0 | 2026-03-12 |  | CONCLUIDO | Juan Florez | Mateo Tabares | Carlos Rodriguez | GIT HUB | Libre | Equipo del proyecto | 6 meses | Borrado seguro digital | Plan del Proyecto | CAD
 |  |  |  | 12/03/2026 – Todos –Juan Sebastian Florez (Versión 1.0, no aprobado por correcciones requeridas)
DOC-024 | Prueba de motores 9 | 2.0 | 2026-03-06 |  | CONCLUIDO | Juan Florez | Mateo Tabares | Carlos Rodriguez | GIT HUB | Libre | Equipo del proyecto | 6 meses | Borrado seguro digital | Plan del Proyecto | CAD
 |  |  |  | 06/03/2026 – Todos –Juan Sebastian Florez (Versión 1.0, no aprobado por correcciones requeridas)
DOC-025 | Prueba de motores 10 | 2.0 | 2026-03-06 |  | CONCLUIDO | Juan Florez | Mateo Tabares | Carlos Rodriguez | GIT HUB | Libre | Equipo del proyecto | 6 meses | Borrado seguro digital | Plan del Proyecto | .py
 |  |  |  | 06/03/2026 – Todos –Juan Sebastian Florez (Versión 1.0, no aprobado por correcciones requeridas)
DOC-026 | Prueba de motores 11 | 2.0 | 2026-03-06 |  | CONCLUIDO | Juan Florez | Mateo Tabares | Carlos Rodriguez | GIT HUB | Libre | Equipo del proyecto | 6 meses | Borrado seguro digital | Plan del Proyecto | .py
 |  |  |  | 06/03/2026 – Todos –Juan Sebastian Florez (Versión 1.0, no aprobado por correcciones requeridas)
DOC-027 | Codigo #1 Camara | 2.0 | 2026-03-06 |  | CONCLUIDO | Juan Florez | Kevin Chala | Carlos Rodriguez | GIT HUB | Libre | Equipo del proyecto | 6 meses | Borrado seguro digital | Plan del Proyecto | .py
 |  |  |  | 03/43/2026 – Todos –Juan Sebastian Florez (Versión 1.0, no aprobado por correcciones requeridas)
DOC-028 | Codigo #2 Camara | 2.0 | 2026-03-06 |  | CONCLUIDO | Juan Florez | Kevin Chala | Carlos Rodriguez | GIT HUB | Libre | Equipo del proyecto | 6 meses | Borrado seguro digital | Plan del Proyecto | .py
 |  |  |  | 06/04/2026 – Todos –Juan Sebastian Florez (Versión 1.0, no aprobado por correcciones requeridas)
DOC-029 | Codigo #3 Camara | 2.0 | 2026-03-06 |  | CONCLUIDO | Juan Florez | Kevin Chala | Carlos Rodriguez | GIT HUB | Libre | Equipo del proyecto | 6 meses | Borrado seguro digital | Plan del Proyecto | .py
 |  |  |  | 06/04/2026 – Todos –Juan Sebastian Florez (Versión 1.0, no aprobado por correcciones requeridas)
DOC-030 | Codigo #4 Camara | 2.0 | 2026-03-06 |  | CONCLUIDO | Juan Florez | Kevin Chala | Carlos Rodriguez | GIT HUB | Libre | Equipo del proyecto | 6 meses | Borrado seguro digital | Plan del Proyecto | .py
 |  |  |  | 06/04/2026 – Todos –Juan Sebastian Florez (Versión 1.0, no aprobado por correcciones requeridas)
DOC-031 | Codigo #1 deteccion de camara | 2.0 | 2026-03-06 |  | CONCLUIDO | Federico Gomez | Mateo Tabares | Carlos Rodriguez | GIT HUB | Libre | Equipo del proyecto | 6 meses | Borrado seguro digital | Plan del Proyecto | .py
 |  |  |  | 06/04/2026 – Todos – Federico Gomez (Versión 1.0, no aprobado por correcciones requeridas)
DOC-032 | Codigo #2 deteccion de camara | 2.0 | 2026-03-06 |  | CONCLUIDO | Federico Gomez | Mateo Tabares | Carlos Rodriguez | GIT HUB | Libre | Equipo del proyecto | 6 meses | Borrado seguro digital | Plan del Proyecto | .py
 |  |  |  | 06/04/2026 – Todos –Federico Gomez (Versión 1.0, no aprobado por correcciones requeridas)
DOC-033 | Codigo #3 deteccion de camara | 2.0 | 2026-03-06 |  | CONCLUIDO | Federico Gomez | Mateo Tabares | Carlos Rodriguez | GIT HUB | Libre | Equipo del proyecto | 6 meses | Borrado seguro digital | Plan del Proyecto | .py
 |  |  |  | 06/03/2026 – Todos –Federico Gomez (Versión 1.0, no aprobado por correcciones requeridas)
DOC-034 | Prueba de motores 12 | 2.0 | 2026-03-06 |  | CONCLUIDO | Juan Florez | Mateo Tabares | Carlos Rodriguez | GIT HUB | Libre | Equipo del proyecto | 6 meses | Borrado seguro digital | Plan del Proyecto | .py
 |  |  |  | 06/04/2026 – Todos –Juan Sebastian Florez (Versión 1.0, no aprobado por correcciones requeridas)
DOC-035 | Acople camara | 2.0 | 2026-05-12 |  | CONCLUIDO | Federico Gomez | Mateo Tabares | Carlos Rodriguez | GIT HUB (https://github.com/kchala12/Grupo-4-direccional-/blob/main/Mecanica/acoples/camara%20acople/dibujo%20camra.pdf) | Libre | Equipo del proyecto | 6 meses | Borrado seguro digital | Plan del Proyecto | .pdf
 |  |  |  | 06/03/2026 – Todos –Federico Gomez (Versión 2.0, aprobado por correcciones requeridas)
DOC-036 | Acople de rueda-motor | 2.0 | 2026-05-12 |  | CONCLUIDO | Federico Gomez | Mateo Tabares | Carlos Rodriguez | GIT HUB (https://github.com/kchala12/Grupo-4-direccional-/blob/main/Mecanica/acoples/acople%20motor/dibujio%20acople.pdf) | Libre | Equipo del proyecto | 6 meses | Borrado seguro digital | Plan del Proyecto | .pdf
 |  |  |  | 06/03/2026 – Todos –Federico Gomez (Versión 2.0, aprobado por correcciones requeridas)
DOC-037 | Soporte de Motor | 2.0 | 2026-05-12 |  | CONCLUIDO | Federico Gomez | Mateo Tabares | Carlos Rodriguez | GIT HUB (https://github.com/kchala12/Grupo-4-direccional-/blob/main/Mecanica/acoples/soporte%20motor/soporte%20motor%20dibujo.pdf) | Libre | Equipo del proyecto | 6 meses | Borrado seguro digital | Plan del Proyecto | .pdf
 |  |  |  | 06/03/2026 – Todos –Federico Gomez (Versión 2.0, aprobado por correcciones requeridas)
DOC-038 | PCB | 2.0 | 2026-04-06 |  | CONCLUIDO | Mateo Tabares | Todo el equipo | Edward Gonzalez | GIT HUB (https://github.com/kchala12/Grupo-4-direccional-/blob/main/Electronica/PCB/Calvos_Proyectointegrador.png) | Libre | Equipo del proyecto | 6 meses | Borrado seguro digital | Plan del Proyecto | Imagen
 |  |  |  | 20/03/2026 (Version 2- Mateo Tabares Gil)
DOC-039 | Soporte Rueda Balinera | 2.0 | 2026-05-12 |  | CONCLUIDO | Federico Gomez | Mateo Tabares | Carlos Rodriguez | GIT HUB (https://github.com/kchala12/Grupo-4-direccional-/blob/main/Mecanica/curpo%20carro/soporte%20rueda%20loca/dbujo%20soporte%20rueda%20loca.pdf) | Libre | Equipo del proyecto | 6 meses | Borrado seguro digital | Plan del Proyecto | .pdf
 |  |  |  | 06/03/2026 – Todos –Federico Gomez (Versión 2.0, aprobado por correcciones requeridas)
DOC-040 | Soporte sensor ultrasonico | 2.0 | 2026-05-12 |  | CONCLUIDO | Federico Gomez | Mateo Tabares | Carlos Rodriguez | GIT HUB (https://github.com/kchala12/Grupo-4-direccional-/blob/main/Mecanica/curpo%20carro/caja%20ultrasonido/caja%20ultrasonido.pdf) | Libre | Equipo del proyecto | 6 meses | Borrado seguro digital | Plan del Proyecto | .pdf
 |  |  |  | 06/03/2026 – Todos –Federico Gomez (Versión 2.0, aprobado por correcciones requeridas)
DOC-041 | Cota del vehiculo | 2.0 | 2026-05-12 |  | CONCLUIDO | Federico Gomez | Mateo Tabares | Carlos Rodriguez | GIT HUB (https://github.com/kchala12/Grupo-4-direccional-/blob/main/Mecanica/curpo%20carro/dibujo%20carro%20cota.pdf) | Libre | Equipo del proyecto | 6 meses | Borrado seguro digital | Plan del Proyecto | .pdf
 |  |  |  | 06/03/2026 – Todos –Federico Gomez (Versión 2.0, aprobado por correcciones requeridas)
DOC-042 | Bitacora semana 12-13 | 2.0 | 2026-05-12 |  | CONCLUIDO | Kevin Chala | Mateo Tabares | Tatiana Rengifo | GIT HUB (https://github.com/kchala12/Grupo-4-direccional-/blob/main/Documentac%C3%ADon/Bitacoras/Bitacora%20Semana%2012%20y%2013.docx%20(2).pdf) | Lectura: Tatiana Rengifo Oviedo, Carlos Andres Rodriguez, Edward Andres Gonzalez Rios Escritura: Mateo Tabares, Juan Florez, Federico Gomez y Kevin Chala | Equipo del proyecto | 6 meses | Borrado seguro digital | Plan del Proyecto | .pdf
 |  |  |  | 17/04/2026 ( Version 2- Kevin Chala- Planeación y ejecución)
DOC-043 | Bitacora semana 14-15 | 2.0 | 2026-05-12 |  | CONCLUIDO | Kevin Chala | Mateo Tabares | Tatiana Rengifo | GIT HUB (https://github.com/kchala12/Grupo-4-direccional-/blob/main/Documentac%C3%ADon/Bitacoras/Bitacora%20Semana%2014%20y%2015.docx.pdf) | Lectura: Tatiana Rengifo Oviedo, Carlos Andres Rodriguez, Edward Andres Gonzalez Rios Escritura: Mateo Tabares, Juan Florez, Federico Gomez y Kevin Chala | Equipo del proyecto | 6 meses | Borrado seguro digital | Plan del Proyecto | .pdf
 |  |  |  | 01/05/2026 ( Version 2- Kevin Chala- Planeación y ejecución)
DOC-044 | Bitacora semana 16-17 | 2.0 | 2026-05-12 |  | CONCLUIDO | Kevin Chala | Mateo Tabares | Tatiana Rengifo | GIT HUB (https://github.com/kchala12/Grupo-4-direccional-/blob/main/Documentac%C3%ADon/Bitacoras/Bitacora%20Semana%2016%20y%2017.docx.pdf) | Lectura: Tatiana Rengifo Oviedo, Carlos Andres Rodriguez, Edward Andres Gonzalez Rios Escritura: Mateo Tabares, Juan Florez, Federico Gomez y Kevin Chala | Equipo del proyecto | 6 meses | Borrado seguro digital | Plan del Proyecto | .pdf
 |  |  |  | 15/05/2026 ( Version 2- Kevin Chala- Planeación y ejecución)
DOC-045 | Manual de Usuario | 2.0 | 2026-05-18 |  | CONCLUIDO | Kevin Chala | Mateo Tabares | Tatiana Rengifo | GIT HUB (https://github.com/kchala12/Grupo-4-direccional-/blob/main/Documentac%C3%ADon/Manual%20de%20Usuario/Manual_de_usuario_IEEE.pdf) | Lectura: Tatiana Rengifo Oviedo, Carlos Andres Rodriguez, Edward Andres Gonzalez Rios Escritura: Mateo Tabares, Juan Florez, Federico Gomez y Kevin Chala | Equipo del proyecto | 6 meses | Borrado seguro digital | Plan del Proyecto | .pdf
 |  |  |  | 18/05/2026 ( Version 2- Kevin Chala- Planeación y ejecución)
DOC-046 | Exposición | 2.0 | 2026-05-18 |  | CONCLUIDO | Kevin Chala | Mateo Tabares | Tatiana Rengifo | GIT HUB (https://github.com/kchala12/Grupo-4-direccional-/blob/main/Documentac%C3%ADon/Presentaciones/JUNIO%202026%20(2).pdf) | Lectura: Tatiana Rengifo Oviedo, Carlos Andres Rodriguez, Edward Andres Gonzalez Rios Escritura: Mateo Tabares, Juan Florez, Federico Gomez y Kevin Chala | Equipo del proyecto | 6 meses | Borrado seguro digital | Plan del Proyecto | .pdf
 |  |  |  | 18/05/2026 ( Version 2- Kevin Chala- Planeación y ejecución)
DOC-047 | Poster | 2.0 | 2026-05-18 |  | CONCLUIDO | Kevin Chala | Mateo Tabares | Tatiana Rengifo | GIT HUB (https://github.com/kchala12/Grupo-4-direccional-/blob/main/Documentac%C3%ADon/Presentaciones/Poster_Robot%20(1).pptx.pdf) | Lectura: Tatiana Rengifo Oviedo, Carlos Andres Rodriguez, Edward Andres Gonzalez Rios Escritura: Mateo Tabares, Juan Florez, Federico Gomez y Kevin Chala | Equipo del proyecto | 6 meses | Borrado seguro digital | Plan del Proyecto | .pdf
 |  |  |  | 18/05/2026 ( Version 2- Kevin Chala- Planeación y ejecución)
DOC-048 | Matriz de Documentos | 2.0 | 2026-05-20 |  | CONCLUIDO | Kevin Chala | Mateo Tabares | Tatiana Rengifo | GIT HUB | Lectura: Tatiana Rengifo Oviedo, Carlos Andres Rodriguez, Edward Andres Gonzalez Rios Escritura: Mateo Tabares, Juan Florez, Federico Gomez y Kevin Chala | Equipo del proyecto | 6 meses | Borrado seguro digital | Plan del Proyecto | .xlsx
 |  |  |  | 18/05/2026 ( Version 2- Kevin Chala- Planeación y ejecución)
DOC-049 | Codigo Principal | 2.0 | 2026-05-20 |  | CONCLUIDO | Juan Florez | Mateo Tabares | Carlos Rodriguez | GIT HUB (https://github.com/kchala12/Grupo-4-direccional-/blob/main/src/principal11.py) | Libre | Equipo del proyecto | 6 meses | Borrado seguro digital | Plan del Proyecto | .py
 |  |  |  | 20/05/2026 – Todos –Juan Sebastian Florez (Versión 1.0, no aprobado por correcciones requeridas)
DOC-050 | Codigo motores | 2.0 | 2026-05-20 |  | CONCLUIDO | Juan Florez | Mateo Tabares | Carlos Rodriguez | GIT HUB (https://github.com/kchala12/Grupo-4-direccional-/blob/main/src/camara_detector27.py) | Libre | Equipo del proyecto | 6 meses | Borrado seguro digital | Plan del Proyecto | .py
 |  |  |  | 20/05/2026 – Todos –Juan Sebastian Florez (Versión 1.0, no aprobado por correcciones requeridas)
DOC-051 | Codigo Cámara | 2.0 | 2026-05-20 |  | CONCLUIDO | Juan Florez | Mateo Tabares | Carlos Rodriguez | GIT HUB (https://github.com/kchala12/Grupo-4-direccional-/blob/main/src/camara_detector27.py) | Libre | Equipo del proyecto | 6 meses | Borrado seguro digital | Plan del Proyecto | .py
 |  |  |  | 20/05/2026 – Todos –Juan Sebastian Florez (Versión 1.0, no aprobado por correcciones requeridas)
DOC-052 | Codigo de Calibración de motores | 2.0 | 2026-05-20 |  | CONCLUIDO | Juan Florez | Mateo Tabares | Carlos Rodriguez | GIT HUB (https://github.com/kchala12/Grupo-4-direccional-/blob/main/src/calibrar_encoders.py) | Libre | Equipo del proyecto | 6 meses | Borrado seguro digital | Plan del Proyecto | .py
 |  |  |  | 20/05/2026 – Todos –Juan Sebastian Florez (Versión 1.0, no aprobado por correcciones requeridas)
DOC-053 | Articulo Publicable | 2.0 | 2026-05-20 |  | CONCLUIDO | Kevin Chala | Mateo Tabares | Tatiana Rengifo | GIT HUB (https://github.com/kchala12/Grupo-4-direccional-/blob/main/Documentac%C3%ADon/Articulo%20Publicable%20CALVOS.pdf) | Libre | Equipo del proyecto | 6 meses | Borrado seguro digital | Plan del Proyecto | .pdf
 |  |  |  | 18/05/2026 ( Version 2- Kevin Chala- Planeación y ejecución)
DOC-053 | Informe final | 2.0 | 2026-05-20 |  | CONCLUIDO | Kevin Chala | Mateo Tabares | Tatiana Rengifo | GIT HUB (https://github.com/kchala12/Grupo-4-direccional-/blob/main/Documentac%C3%ADon/Informes/Informe_Final%20C.A.L.V.O.S%20VS%202.0.pdf) | Libre | Equipo del proyecto | 6 meses | Borrado seguro digital | Plan del Proyecto | .pdf
 |  |  |  | 18/05/2026 ( Version 2- Kevin Chala- Planeación y ejecución)
DOC-053 | Pruebas de motores #9 | 2.0 | 2026-06-04 |  | CONCLUIDO | Juan Florez | Mateo Tabares | Carlos Rodriguez | GIT HUB (https://github.com/kchala12/Grupo-4-direccional-/blob/main/src/motor_control9.py) | Libre | Equipo del proyecto | 6 meses | Borrado seguro digital | Plan del Proyecto | .py
 |  |  |  | 18/05/2026 ( Version 2- Kevin Chala- Planeación y ejecución)
DOC-053 | Camara # 28 | 2.0 | 2026-06-04 |  | CONCLUIDO | Juan Florez | Mateo Tabares | Carlos Rodriguez | GIT HUB (https://github.com/kchala12/Grupo-4-direccional-/blob/main/src/camara_detector28.py) | Libre | Equipo del proyecto | 6 meses | Borrado seguro digital | Plan del Proyecto | .py
 |  |  |  | 18/05/2026 ( Version 2- Kevin Chala- Planeación y ejecución)
DOC-054 | Principal #21 | 2.0 | 2026-06-04 |  | CONCLUIDO | Juan Florez | Mateo Tabares | Carlos Rodriguez | GIT HUB (https://github.com/kchala12/Grupo-4-direccional-/blob/main/src/principal21.py) | Libre | Equipo del proyecto | 6 meses | Borrado seguro digital | Plan del Proyecto | .py
 |  |  |  | 18/05/2026 ( Version 2- Kevin Chala- Planeación y ejecución)
DOC-055 | Cota del vehiculo final | 2.0 | 2026-05-12 |  | CONCLUIDO | Federico Gomez | Mateo Tabares | Carlos Rodriguez | GIT HUB (https://github.com/kchala12/Grupo-4-direccional-/blob/main/Mecanica/curpo%20carro/dibujo%20carro.pdf) | Libre | Equipo del proyecto | 6 meses | Borrado seguro digital | Plan del Proyecto | .pdf
 |  |  |  | 06/03/2026 – Todos –Federico Gomez (Versión 2.0, aprobado por correcciones requeridas)

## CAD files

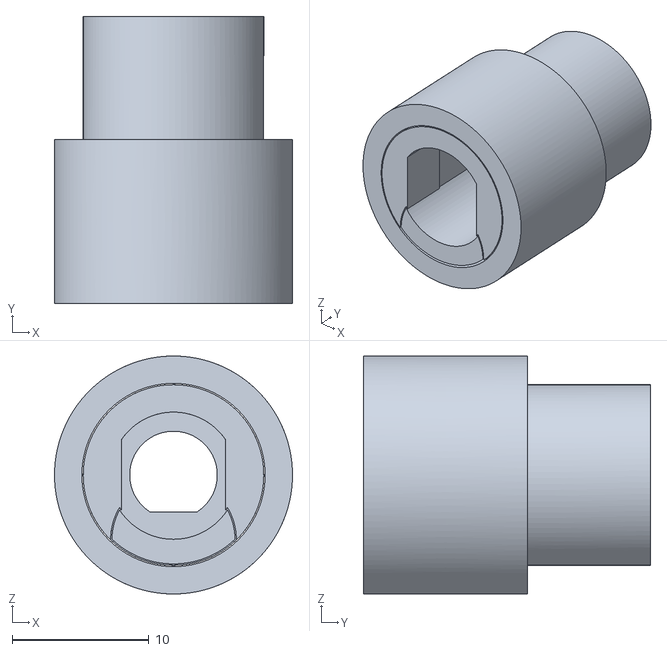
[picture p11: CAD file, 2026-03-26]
Mecanica/acoples/acople motor/acople motor.stl
17.4 x 21.0 x 17.4

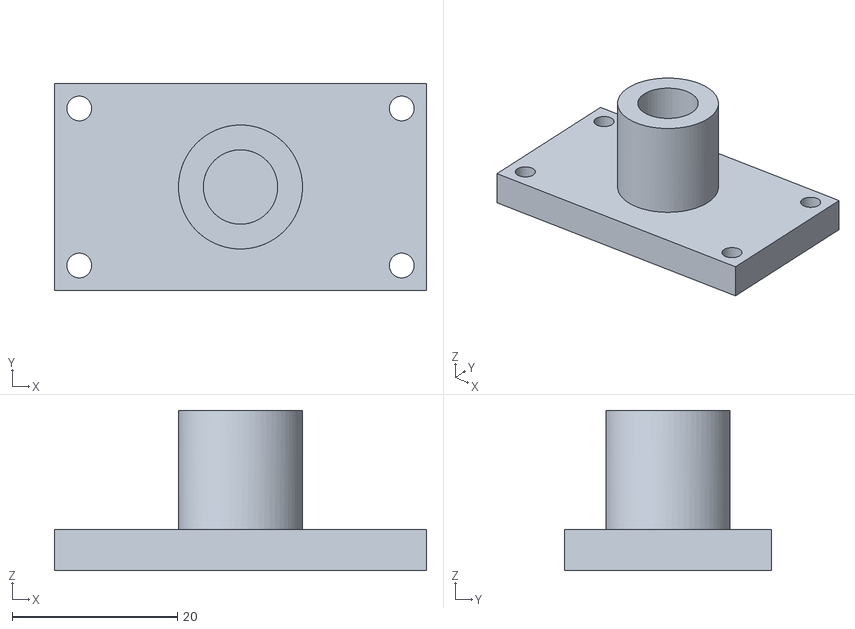
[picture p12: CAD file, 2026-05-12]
Mecanica/acoples/camara acople/base camara/base camara.stl
45.0 x 25.0 x 19.4

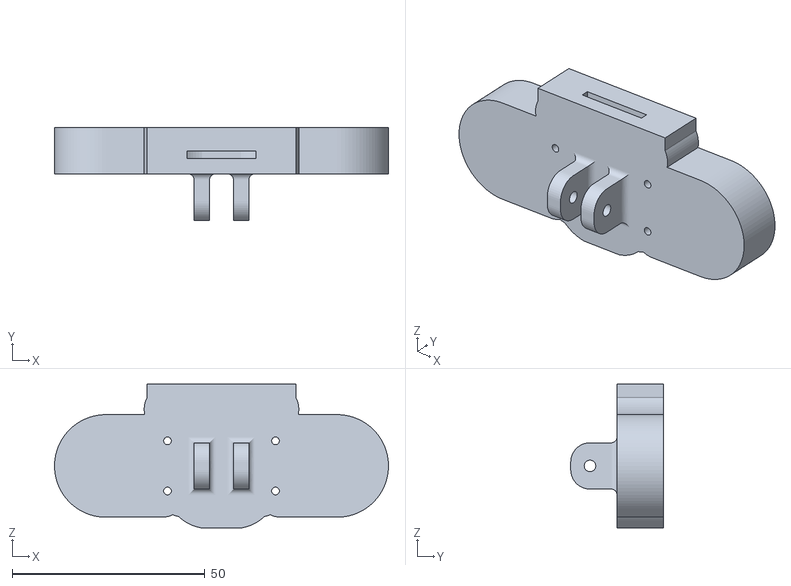
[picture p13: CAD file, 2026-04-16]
Mecanica/acoples/camara acople/ensamble camara/camara.stl
86.6 x 24.0 x 37.2

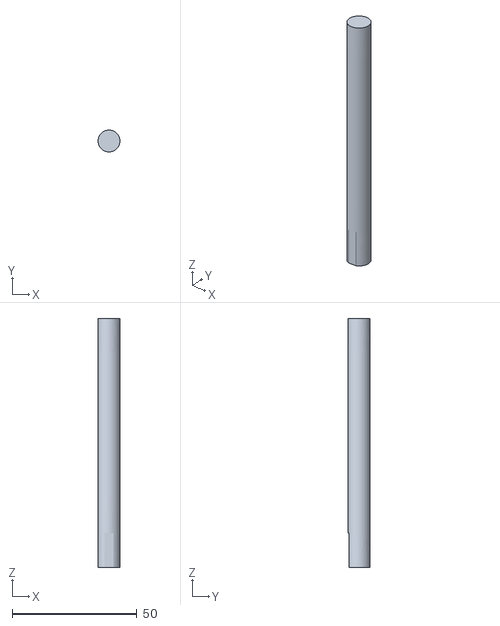
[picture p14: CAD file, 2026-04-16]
Mecanica/acoples/camara acople/poste camara/poste camara.stl
8.79 x 8.80 x 100.0

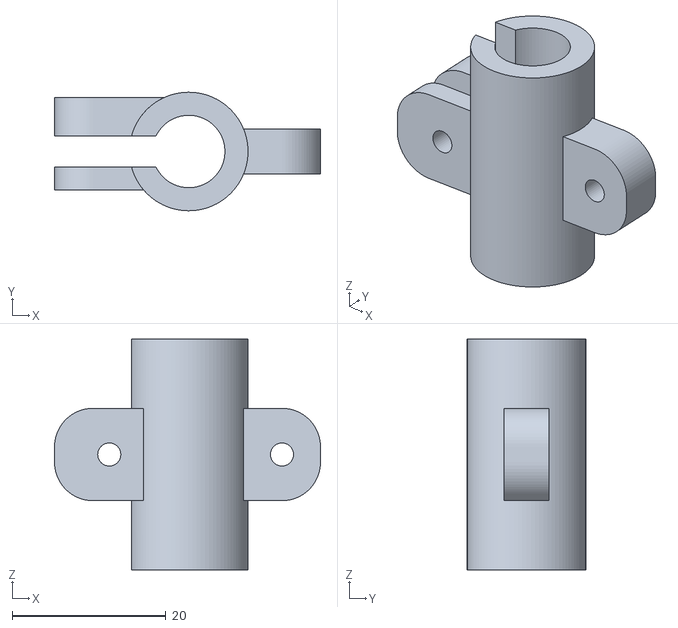
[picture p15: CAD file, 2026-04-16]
Mecanica/acoples/camara acople/union camara poste/union camara poste.stl
34.5 x 15.4 x 30.0

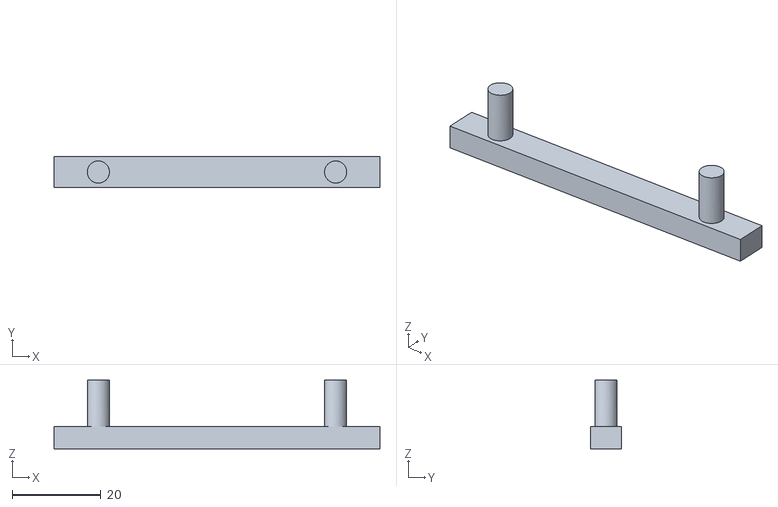
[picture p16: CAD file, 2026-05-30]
Mecanica/acoples/manija parte trasera/manija parte trasera.stl
73.5 x 7.00 x 15.5

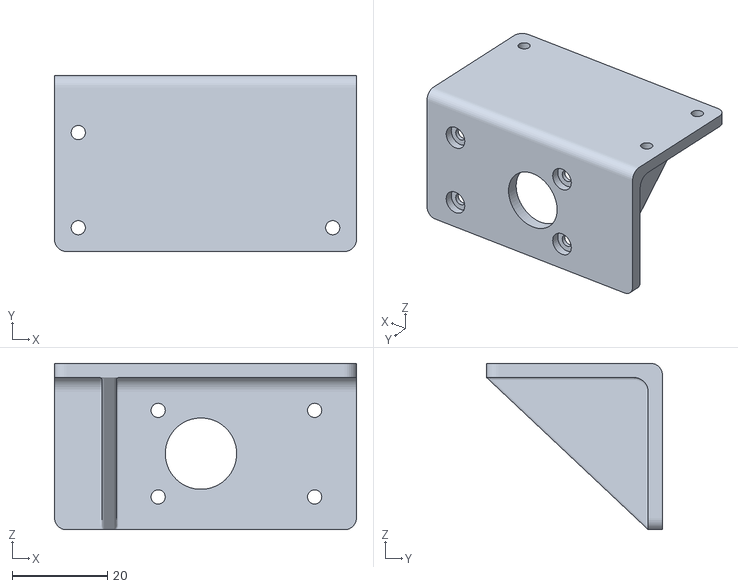
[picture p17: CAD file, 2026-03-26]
Mecanica/acoples/soporte motor/soporte motor.stl
63.5 x 37.0 x 35.0

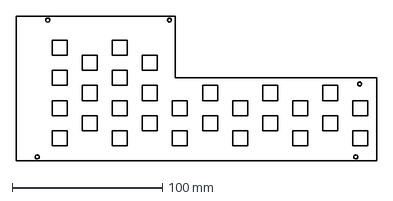
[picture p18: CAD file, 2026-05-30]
Mecanica/curpo carro/corte/pared 1.dxf
240.0 x 96.0 mm

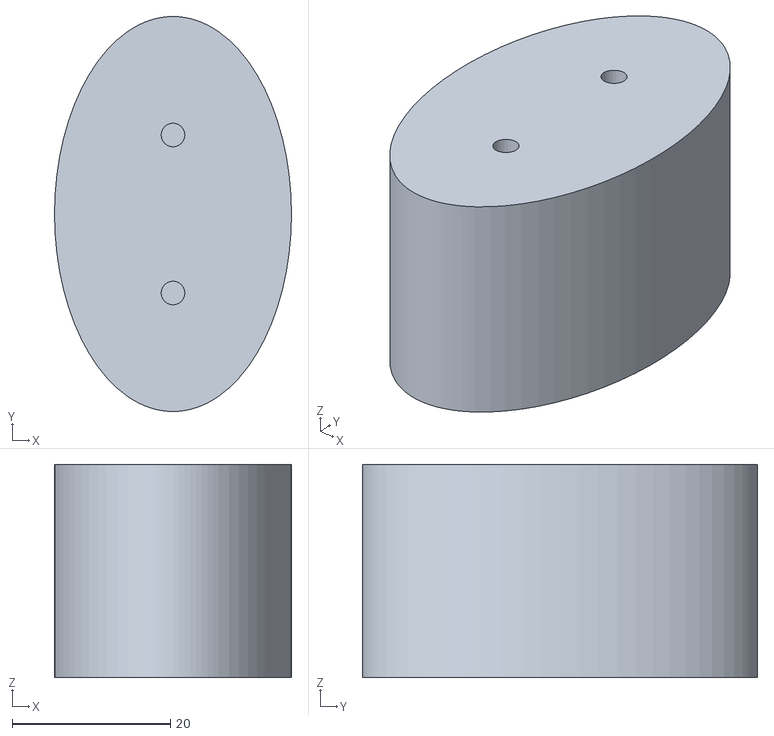
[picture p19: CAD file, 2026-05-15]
Mecanica/curpo carro/soporte rueda loca/soporte rueda loca.stl
30.0 x 50.0 x 27.0

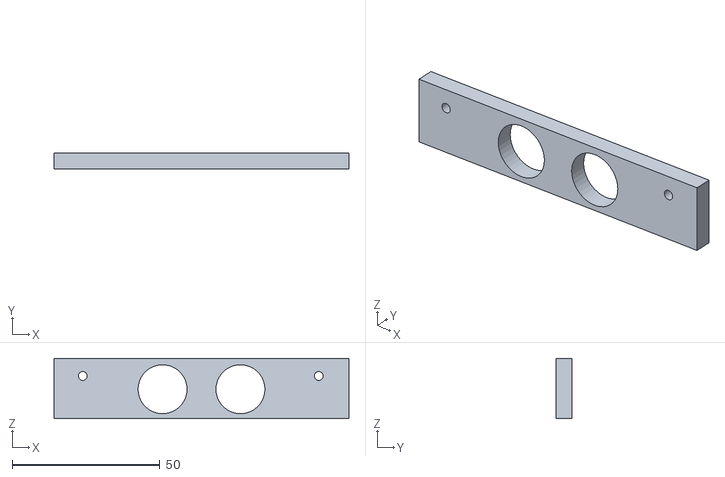
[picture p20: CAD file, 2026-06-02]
Mecanica/curpo carro/ultra cople/pared ultra.stl
100.0 x 5.50 x 20.5

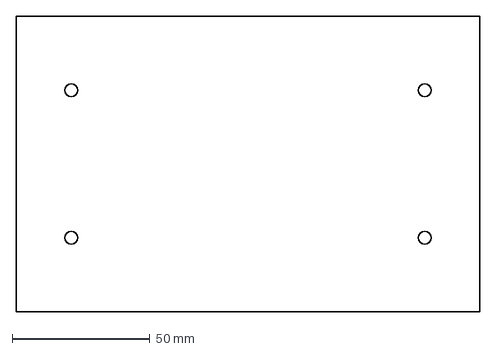
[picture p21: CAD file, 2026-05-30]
Mecanica/curpo carro/corte/pared trasera.dxf
168.0 x 107.0 mm

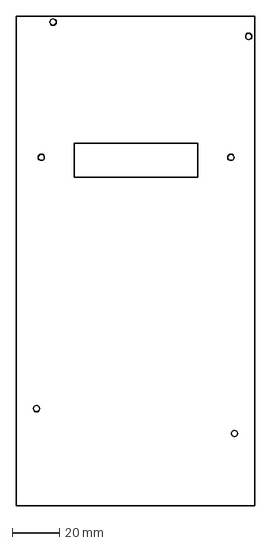
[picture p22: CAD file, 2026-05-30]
Mecanica/curpo carro/corte/sup carga.dxf
100.5 x 206.5 mm

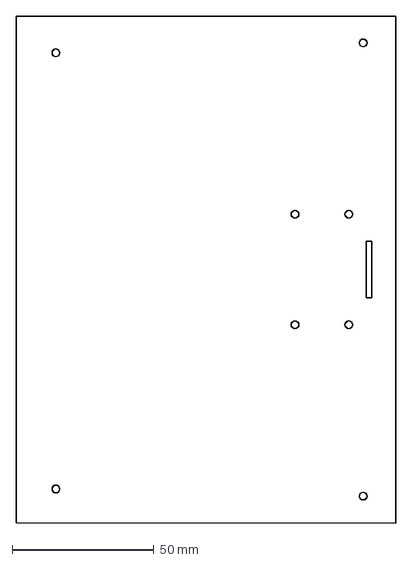
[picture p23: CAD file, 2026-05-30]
Mecanica/curpo carro/corte/sup camara.dxf
134.0 x 179.0 mm

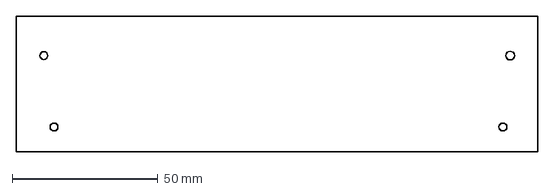
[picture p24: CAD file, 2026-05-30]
Mecanica/curpo carro/corte/pared anterior ultra.dxf
179.0 x 46.5 mm

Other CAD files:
Mecanica/curpo carro/corte/pared 2.dxf
Mecanica/curpo carro/corte/pared frontal.dxf
Mecanica/curpo carro/corte/base.dxf
Mecanica/acoples/acople motor/acople motor.f3z
Mecanica/acoples/camara acople/base camara/base camara.f3d
Mecanica/acoples/camara acople/ensamble camara/camara.f3z
Mecanica/acoples/camara acople/poste camara/poste camara.f3d
Mecanica/acoples/camara acople/union camara poste/union camara poste.f3d
Mecanica/acoples/manija parte trasera/manija parte trasera.f3d
Mecanica/acoples/soporte motor/soporte motor.f3d
Mecanica/objetos/camara/camara objeto.f3d
Mecanica/objetos/motor/motor.f3d
Mecanica/objetos/rasberry/RaspberryPi.f3d
Mecanica/objetos/reductor 8A/reductor de 8A.f3d
Mecanica/objetos/regulador/regulador de voltaje.f3d
Mecanica/objetos/rueda loca/ruedaLoca.f3d
Mecanica/objetos/ultrasonido/ultrasonido objeto.f3d

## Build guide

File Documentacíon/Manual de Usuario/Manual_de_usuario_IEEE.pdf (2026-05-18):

Universidad Tecnológica de Pereira — Ingeniería Mecatrónica — 2026

# Manual de Usuario: Control Autónomo Logístico Vehicular Optimizado de Suministros (C.A.L.V.O.S.)

Mateo Tabares Gil, Electrónica, Federico Gómez Lotero, Mecánica,
Juan Sebastián Flórez Molina, Programación, Kevin Andrés Chala González, Documentación Osiel Arbeláez Salazar, Director de Carrera, Angie Tatiana Rengifo Oviedo, Asesora, Carlos Andrés Rodríguez Pérez, Asesor, Edward Andrés González Ríos, Asesor Programa de Ingeniería Mecatrónica, Universidad Tecnológica de Pereira, Pereira, Colombia

Resumen
Este documento hace parte del Manual de Usuario del Robot Móvil Autónomo desarrollado en la Universidad Tecnológica de Pereira. Proporciona una guía paso a paso para la conexión SSH desde VSCode, el encendido del sistema, los procedimientos de operación, la resolución de errores comunes y tres casos de prueba funcionales que validan las capacidades principales del robot desde la perspectiva del usuario: navegación guiada por códigos QR, ciclo completo de estaciones y detección de obstáculos.
Palabras clave— navegación autónoma, códigos QR, visión artificial, SSH, manual de usuario, casos de prueba.

### I. INTRODUCCIÓN

Este documento constituye una sección del Manual de Usuario del Robot Móvil Autónomo mejor conocido por el acrónimo c.a.l.v.o.s desarrollado por el Grupo 4 del Semestre Integrador de la Universidad Tecnológica de Pereira. Su propósito es guiar al usuario en el proceso de conexión, puesta en marcha y operación del sistema, así como documentar los casos de prueba que validan el correcto funcionamiento del robot desde la perspectiva del usuario.

El Robot emplea visión artificial y códigos QR como mecanismo de navegación en un entorno controlado, transportando cargas de hasta 1 kg entre estaciones de carga y descarga predefinidas. El sistema integra una Raspberry Pi 5 como unidad de cómputo principal, un ESP32 como controlador de bajo nivel, cámara IMX219, motores JGY-370 con encoder, puente H TB6612 y batería LiPo 11.1 V.

### II. REQUISITOS PREVIOS SOFTWARE

A) Hardware necesario
Para operar el robot correctamente el usuario debe disponer de:
- Computador con Windows 10/11, macOS o Linux.
- Conectividad Ethernet o Wi-Fi en la misma subred del robot.
- Visual Studio Code instalado.
- Extensión Remote – SSH
(ms-vscode-remote.remote-ssh).
- Cargador LiPo compatible
B) Configuración de red
La Raspberry Pi opera con IP estática asignada en la red del laboratorio. La dirección por defecto configurada durante el desarrollo es:
192.168.0.103 | usuario: Grupo-4
La contraseña de acceso es suministrada por el equipo de desarrollo. Verifique con el encargado del laboratorio antes de iniciar.

### III. CONEXIÓN SSH DESDE VSCODE

A) Instalación de la extensión Remote – SSH
1. Abra VSCode y acceda al panel de Extensiones (Ctrl + Shift + X).
2. Busque Remote - SSH y seleccione la extensión publicada por Microsoft.
3. Haga clic en Instalar. Al finalizar, aparecerá el ícono >< en la esquina inferior izquierda.
B) Agregar el host del robot
4. Haga clic en el ícono >< (esquina inferior izquierda de VSCode).
5. Seleccione Configure SSH Hosts y luego Add New SSH Host.
6. Ingrese el comando de conexión:
ssh Grupo-4@192.168.0.103
7. Cuando VSCode solicite el archivo de configuración, seleccione: C:\Users\<usuario>\.ssh\config
C) Establecer la conexión
8. Abra la paleta de comandos (Ctrl + Shift + P) y seleccione Remote-SSH: Connect to Host.
9. Seleccione 192.168.0.103 en el listado.
10. Ingrese la contraseña del usuario Grupo-4 cuando se solicite.
Manual de Usuario — AGV Robot Móvil Autónomo | 1

11. Confirmación: la barra inferior izquierda mostrará en azul SSH: Grupo-4 cuando la conexión sea exitosa.

### IV. ENCENDIDO Y PUESTA EN MARCHA

A) Encendido físico del robot
12. Conecte la batería LiPo al circuito de potencia (conector XT90).
13. Asegúrese de que el área de desplazamiento esté libre de obstáculos.
14. Active el interruptor principal ubicado en el panel lateral del chasis.
15. Aguarde 1 – 2 minutos a que la Raspberry Pi complete el arranque del sistema operativo.
B) Ejecución del programa principal
16. En VSCode, haga clic en Open Folder.
17. Seleccione la carpeta Grupo-4-direccional- y dentro de ella abra la carpeta src.
18. Haga clic sobre el archivo Principal 5 para abrirlo en el editor.
19. Abra la terminal integrada (Ctrl + `) y ejecute el archivo.
20. Cuando el sistema esté listo, introduzca el comando go en la terminal y presione Enter para iniciar el recorrido.

### V. REQUISITOS PREVIOS HARDWARE

Antes de la puesta en marcha del robot se debe tener en cuenta las siguientes condiciones para el correcto funcionamiento:

A) Pista
La bodega debe contar con una pista demarcada por cinta roja como cartel exterior siendo la separación entre carril izquierdo y derecho por una cinta amarilla, además de acomodar los códigos Qr en sitios como los mostrados a continuación.

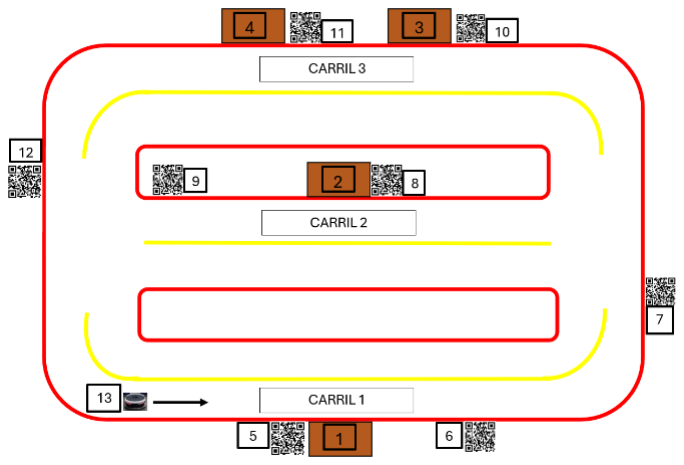
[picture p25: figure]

Fig. 1. Imagen ilustrativa de pista como referencia.

B) Iluminación

Se requiere una fuente de iluminación estable durante toda la operación y puesta en funcionamiento del robot, con el fin de garantizar el correcto desempeño del sistema de navegación y visión artificial.

C) Uso de entornos planos

Es fundamental que el entorno de trabajo cuente con una superficie plana y uniforme, con el fin de garantizar el correcto funcionamiento y desplazamiento del robot durante su operación.

D) Códigos

Además de la pista de desplazamiento, el sistema requiere la implementación de códigos QR estratégicamente ubicados a lo largo de la trayectoria del robot. Estos códigos constituyen uno de los principales mecanismos de navegación y referencia del sistema, ya que permiten al robot obtener información específica relacionada con las acciones que debe ejecutar durante su recorrido.

### VI. CARACTERÍSTICAS GENERALES DEL ROBOT

El robot móvil autónomo C.A.L.V.O.S. fue diseñado para operar en entornos industriales controlados, realizando tareas de transporte automatizado de materiales mediante navegación autónoma basada en visión artificial y lectura de códigos QR. El sistema cuenta con una capacidad máxima de carga de 1 kg y está orientado al desplazamiento entre estaciones predefinidas con tracción diferencial. Para colocar en contexto algunas de las características de los componentes del robot son:

A) Raspberry Pi 5 (8 GB)
La Raspberry Pi 5 corresponde a la unidad principal de procesamiento del robot y opera con un voltaje de 5 V DC y una corriente recomendada de 5 A, alcanzando un consumo aproximado de hasta 25 W. Cuenta con un procesador Quad-Core ARM Cortex-A76 con frecuencia de 2.4 GHz y 8 GB de memoria RAM, lo que le permite ejecutar tareas de navegación autónoma, visión artificial y procesamiento de datos en tiempo real. Además, incorpora conectividad Wi-Fi, Bluetooth, Ethernet y 40 pines GPIO para integración con otros componentes electrónicos.

B) ESP 32
El ESP32 funciona como microcontrolador auxiliar para el control de bajo nivel y la comunicación con sensores y actuadores. Opera internamente a 3.3 V DC, aunque puede alimentarse mediante una entrada USB tipo C de 5 V. Su consumo de corriente varía entre 80 mA y 260 mA dependiendo de la carga de trabajo. Dispone de un procesador de doble núcleo con frecuencias de hasta 240 MHz, además de conectividad Wi-Fi y Bluetooth integrada, siendo ampliamente utilizado en aplicaciones de automatización y robótica.
C) Cámara IMX219
La cámara IMX219 es el dispositivo encargado de capturar imágenes para la detección de códigos QR y navegación autónoma. Opera a un voltaje de 3.3 V y presenta un consumo aproximado entre 200 mA y 250 mA. Posee una resolución máxima de 8 megapíxeles y capacidad de grabación de video en resolución Full HD 1080p a 30 fps. La comunicación con la Raspberry Pi se realiza mediante la interfaz CSI, permitiendo una transmisión rápida y eficiente de imágenes.
D) Batería LiPo 5000mAh
La batería LiPo utilizada en el robot proporciona la alimentación principal del sistema. Posee una capacidad de 5000 mAh, permitiendo una autonomía de alrededor de 6 horas continúas. Su tecnología de polímero de litio ofrece alta densidad energética y estabilidad durante la descarga. Además, soporta tasas de descarga entre 20C y 30C, permitiendo corrientes máximas teóricas entre 100 A y 150 A. El sistema utiliza conector XT90 para la conexión al circuito de potencia.
E) Motores JGY-370 con Encoder
Los motores JGY-370 son utilizados para el desplazamiento del robot y operan en rangos de 6 V. Presentan un consumo nominal aproximado entre 300 mA, aunque pueden alcanzar corrientes de arranque de hasta 2 A. Incorporan una caja reductora metálica y encoder integrado, lo que permite realizar control preciso de velocidad y posición durante la navegación autónoma.
F) Puente H TB6612
El puente H TB6612 es el controlador encargado de regular el sentido de giro y velocidad de los motores DC del robot. Opera con un voltaje lógico entre 2.7 V y 5.5 V, mientras que el voltaje de alimentación de motores puede variar entre 4.5 V y 13.5
V. Soporta corrientes continuas de hasta 1.2 A por canal y corrientes pico de 3.2 A, utilizando señales PWM para el control de velocidad.
G) Sensores Ultrasónicos HC-SR04
Los sensores ultrasónicos HC-SR04 permiten detectar obstáculos durante la trayectoria del robot. Operan a un voltaje de 5 V DC y consumen aproximadamente 15 mA. Poseen un rango de medición entre 2 cm y 400 cm con una precisión aproximada de ±3 mm, utilizando señales ultrasónicas de 40 kHz para calcular distancias.

### VII. MANTENIMIENTO BASICO

A) Inspección general del sistema
Antes de cada operación, realizar una inspección visual del robot para verificar el estado general de la estructura, conexiones eléctricas, ruedas, sensores y componentes electrónicos. Confirmar que no existan piezas sueltas, cables dañados o señales de desgaste.
B) Verificación de la batería
Comprobar el nivel de carga de la batería LiPo antes de poner en funcionamiento el robot. Evitar descargar completamente la batería y utilizar únicamente cargadores compatibles. Revisar periódicamente que la batería no presente hinchamientos, sobrecalentamiento o daños físicos.
C) Limpieza de la cámara y sensores
Mantener limpia la cámara IMX219 y los sensores ultrasónicos HC-SR04 para garantizar una correcta detección de códigos QR y obstáculos. Utilizar un paño suave y seco para retirar polvo o suciedad acumulada.
E) Revisión del sistema de tracción
Inspeccionar periódicamente el estado de las ruedas omnidireccionales y motores JGY-370. Verificar que no existan obstrucciones, desgaste excesivo o pérdida de estabilidad durante el desplazamiento.
F) Verificación de conexiones eléctricas
Revisar que los conectores, terminales y cables del sistema electrónico permanezcan correctamente ajustados. Confirmar el correcto funcionamiento de la Raspberry Pi, ESP32 y puente H TB6612 antes de iniciar operaciones.
G) Mantenimiento de la pista y entorno
Mantener limpia la pista de navegación y verificar que las cintas de demarcación y códigos QR permanezcan visibles y correctamente posicionados. Confirmar que el área de trabajo cuente con iluminación adecuada y superficie plana.
H) Almacenamiento seguro
Cuando el robot no se encuentre en operación, almacenar el sistema en un lugar seco, limpio y libre de humedad. Desconectar la batería y proteger los componentes electrónicos de polvo o golpes.

### VIII. DETENCIÓN DEL ROBOT

El robot dispone de tres mecanismos de parada:
- Botón físico de corriente ubicado en la parte posterior del chasis.
- Interrupción del proceso desde la terminal SSH: Ctrl + C.
- Comando por terminal: escribir stop y presionar Enter.

### IX. ERRORES COMUNES Y SOLUCIÓN

TABLA I
ERRORES DE CONEXIÓN SSH
Error | Causa probable | Solución
Connection refused / timed out | Raspberry Pi apagada o en proceso de arranque. | Encienda el robot, espere 30 s y ejecute: ping 192.168.0.103
Permission denied | Contraseña o usuario incorrecto. | Verifique usuario (Grupo-4) y contraseña. Reintente la conexión.
Network unreachable | Dispositivos en subredes distintas. | Confirme que el PC y el robot estén en la misma red. Use ipconfig / ip a para verificar.

TABLA II
ERRORES DEL SISTEMA EN OPERACIÓN
Error | Causa probable | Solución
Camera not detected / picamera2 error | Cable flex CSI desconectado o dañado. | Apague el robot, reinserte el cable flex y verifique con vcgencmd get_camera.
Apagado repentino | Batería descargada. | Revise LED de Raspberry Pi: rojo → cargue la batería; verde → contacte soporte.
Comando stop no responde | Pérdida de conexión SSH. | Presione el botón físico de corriente.
Error | Causa probable | Solución
| | Espere 2 min y reinicie.
Detección de obstáculos invisibles | Baja iluminación o pista sucia. | Detenga el robot, limpie la pista y mejore la iluminación del área.
No detección de obstáculos / QR | Descalibración del sistema. | Detenga con Ctrl + C y vuelva a ejecutar Principal 5.

### X. CASOS DE PRUEBA DE FUNCIONALIDAD PRINCIPAL

Los casos de prueba descritos a continuación validan las funcionalidades principales del robot desde la perspectiva del usuario. Cada caso documenta objetivo, requisitos previos, pasos de ejecución, resultado esperado, resultado real obtenido y estado final de la prueba.

TABLA III
CASO DE PRUEBA 001 — VUELTA A TRAVÉS DE LA PISTA
ID | 001
Objetivo | Verificar que al ejecutar el programa, el robot realiza un recorrido completo sobre la pista siguiendo las líneas de demarcación, efectuando correctamente los cambios de dirección y curvas establecidas.
Requisitos previos | Robot ubicado en la recta de inicio, sin obstáculos frente a él. Programa Principal 5 abierto en VSCode.
Pasos | 1. Conectarse al robot por SSH (Sección III). 2. Abrir la carpeta src y el archivo Principal 5 (Sección IV-B). 3. En la terminal SSH introducir el comando go y presionar Enter. 4. Observar que el robot inicia el desplazamiento sobre la pista. 5. Verificar que el robot completa una vuelta completa sin desviarse.
Resultado esperado | El robot completa una vuelta a la pista de forma autónoma, respetando las curvas y cambios de dirección predefinidos.

TABLA IV
CASO DE PRUEBA 002 — DETECCIÓN Y DETENCIÓN ANTE OBSTÁCULOS
ID | 002
Objetivo | Verificar que el robot detecta un obstáculo interpuesto en su trayectoria durante la navegación y se detiene antes de colisionar, protegiendo la integridad del robot y del entorno.

ID | 002
Requisitos previos | Robot en plena operación de navegación autónoma sobre la pista. Sensores ultrasónicos HC-SR04 operativos.
Pasos | 1. Iniciar el ciclo de operación (Sección IV-B, comando go). 2. Con el robot en movimiento, colocar un obstáculo sólido frente a su trayectoria. 3. Esperar a que el obstáculo quede en el rango de 18 – 25 cm del sensor. 4. Verificar en la terminal SSH que se registre el evento de detección. 5. Retirar el obstáculo y verificar que el robot reanuda la navegación.
Resultado esperado | El robot detecta el obstáculo dentro del rango configurado, se detiene sin colisionar y reanuda el recorrido al despejarse el camino. La terminal registra el evento.

TABLA V
CASO DE PRUEBA 003 — DETECCIÓN DE CÓDIGOS QR EN MOVIMIENTO
ID | 003
Objetivo | Verificar que el robot detecta correctamente los códigos QR distribuidos a lo largo de la pista mientras navega y ejecuta la acción correspondiente a cada código.
Requisitos previos | Robot en plena operación de navegación autónoma. Códigos QR colocados en las posiciones predefinidas de la pista.
Pasos | 1. Iniciar el ciclo de operación (Sección IV-B, comando go). 2. Observar el comportamiento del robot al pasar sobre cada código QR. 3. Verificar en la terminal SSH los mensajes de detección de cada QR. 4. Confirmar que el robot ejecuta la acción asignada a cada código.
Resultado esperado | El sistema registra en terminal la detección de cada código QR y ejecuta la acción asociada (cambio de dirección, descarga, etc.) sin intervención del usuario.

### XI. REFERENCIAS

[1] Gallardo Gómez, L. (2017). Desarrollo de un robot de fútbol con detección de pelotas mediante visión artificial. Universidad de Sevilla, Escuela Técnica Superior de Ingeniería.
[2] Gallardo Gómez, L. (2017). Aplicación de visión por computador y machine learning al guiado de un robot móvil basado en Raspberry Pi. Universidad de Sevilla, Escuela Técnica Superior de Ingeniería.
[3] Martínez Martínez, A. (2022). Construcción de un coche de conducción autónomo robótico. Universidad Politécnica de València.
[4] Gómez Patiño, D. A. (2019). Diseño e implementación de un robot móvil autónomo para el transporte de materiales. Universidad Tecnológica de Pereira.
[5] Ferreira Neto, N. A. (2022). Visual-based perception for autonomous vehicles in of -road environment using deep learning. Programa de Pós-Graduação em Engenharia Elétrica.

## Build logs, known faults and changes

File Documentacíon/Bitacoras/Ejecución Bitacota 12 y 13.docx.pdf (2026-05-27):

## INGENIERÍA MECATRÓNICA

SEMESTRE INTEGRADOR | CÓDIGO | FI-F-001
BITÁCORA | VERSIÓN | 3

## IDENTIFICACIÓN DEL PROYECTO

## NOMBRE DEL PROYECTO: C.A.L.V.O.S

## INTEGRANTES DEL EQUIPO

NOMBRE | APELLIDOS | CÓDIGO | ROL EN EL PROYECTO
Federico | Gomez Lotero | 1085717866 | Diseño Mecánico
NOMBRE | APELLIDOS | CÓDIGO | ROL EN EL PROYECTO
Juan Sebastian | Flores Molina | 1081054047 | Programación
NOMBRE | APELLIDOS | CÓDIGO | ROL EN EL PROYECTO
Kevin Andres | Chala Gonzalez | 1128904330 | Documentación
NOMBRE | APELLIDOS | CÓDIGO | ROL EN EL PROYECTO
Mateo | Tabares Gil | 1087990038 | Diseño Electrónico

## FECHA DE ENTREGA (DD/MM/AA):

## SEMANA NO: 12 y 13 RESPONSABLE DEL REGISTRO: Juan Florez

ETAPA/FASE DEL PROYECTO: Pruebas y refinamiento.

## PLANEACIÓN

## OBJETIVOS (Definidos en la reunión de planeación):

1. Evaluar el desempeño del sistema mediante pruebas de velocidad, con el fin de identificar posibles mejoras en la eficiencia y tiempos de respuesta del proceso.
2. Verificar la funcionalidad y precisión del posicionamiento, asegurando que las operaciones de carga y descarga se realicen de manera segura y sin errores.
3. Analizar los resultados obtenidos en las pruebas realizadas, para proponer ajustes técnicos que mejoren el rendimiento general del sistema.
ACTIVIDAD | FECHA INICIO | FECHA FIN | MATERIALES | PRESUPUESTO | RIESGOS POTENCIALES | ALTERNATIVAS | ENTREGABLE | RESPONSABLE
Posicionami ento para carga y descarga | 20/04/26 | 24/04/26 | Computador, visual studio | N/A | Error en alineación del sistema, fallos en la calibración, retrasos operativos | Recalibración del sistema, pruebas manuales, ajuste de parámetros | Medio | Sistema de posicionamien to funcional y validado
Pruebas de velocidad | 27/04/202 6 | 01/05/26 | Computador, GITHUB | N/A | Datos inconsistentes | Repetición de pruebas, uso de | Medio

SEMESTRE INTEGRADOR | CÓDIGO | FI-F-001
BITÁCORA | VERSIÓN | 3
| | | | | , fallos en medición, errores de ejecución | herramientas de medición adicionales | | Reporte de resultados de pruebas de velocidad
Bitácora | 20/04/202 6 | 01/05/26 | Computador, documentos de google | N/A | Pérdida de información, registros incompletos | Copias de seguridad, uso de herramientas digitales de respaldo | Bajo | Registro documenta do de actividades realizadas

## EJECUCIÓN

ACTIVIDAD | FECHA INICIO | FECHA FIN | OPORTUNIDADES DE MEJORA O DESAFÍOS ENCONTRADOS | ACCIONES CORRECTIVAS O DE MEJORA | ESTADO DE ENTREGABLE | RESPONSABLE
Posicionamient o para carga y descarga | 20/04/26 | 24/04/26 | Demoras en el posicionamiento de vehículos y falta de señalización adecuada en la zona de trabajo. | Implementación de señalización y capacitación al personal en maniobras seguras y eficientes. | En Proceso | Mateo Tabares Gil
Pruebas de velocidad | 27/04/2026 | 01/05/26 | Variabilidad en resultados por condiciones externas y falta de estandarización en el proceso de medición. | Estandarizar el protocolo de pruebas y controlar variables externas para mejorar la precisión de resultados. | En proceso | Kevin Chala
Bitácora | 20/04/2026 | 01/05/26 | Registros incompletos y falta de actualización constante de la información. | Implementar formato estándar y asignar responsable para el diligenciamiento diario. | Terminado | Juan Flórez

## ANÁLISIS DE CAUSA RAÍZ DESAFÍOS ENCONTRADOS:

Durante la semana 12, en el desarrollo de las pruebas de velocidad, se identificó una falla crítica en el sistema. Uno de los motores se detuvo de manera repentina y, tras la inspección de la estructura, se determinó que el encoder correspondiente se había quemado, dejándolo completamente inoperativo.

Como consecuencia de esta falla, las pruebas de velocidad se vieron interrumpidas, generando retrasos tanto en su ejecución como en la programación del posicionamiento del robot.

SEMESTRE INTEGRADOR | CÓDIGO | FI-F-001
BITÁCORA | VERSIÓN | 3

### Problema:

El motor se detuvo de forma repentina durante las pruebas de velocidad debido a que el encoder se quemó.

### - ¿Por qué se detuvo el motor?

Porque el encoder se quemó, dejando el sistema sin retroalimentación de posición.

### - ¿Por qué se quemó el encoder?

Porque recibió un voltaje o corriente inadecuada.

### - ¿Por qué recibió un voltaje/corriente inadecuada?

Debido a una mala conexión en el circuito eléctrico.

### - ¿Por qué existía una mala conexión en el circuito?

Porque el cableado no estaba correctamente asegurado ni verificado.

### - ¿Por qué no se verificó correctamente el cableado?

Porque no se siguió un procedimiento estandarizado de revisión antes de la puesta en marcha.

### - ¿Por qué no existe o no se aplicó un procedimiento estandarizado?

Porque no se habían definido protocolos claros de inspección eléctrica para las pruebas.

### - ¿Por qué no se habían definido estos protocolos?

Porque no se contempló la necesidad de estandarización en la fase de planificación del proyecto.

## EVIDENCIA (FOTOGRAFÍA Y ENLACE A REPOSITORIO):

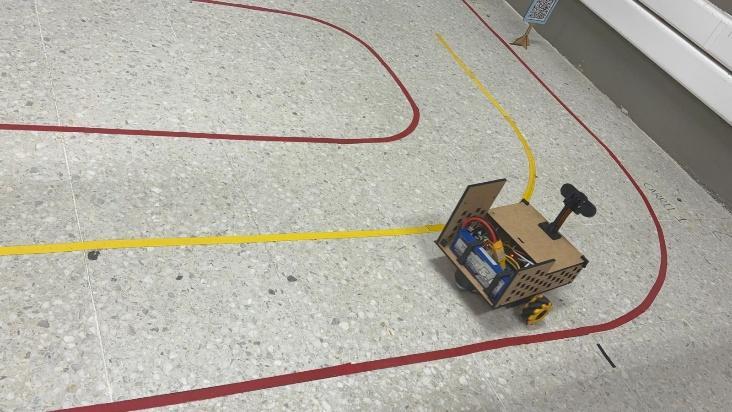
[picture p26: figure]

Pruebas de Velocidad luego de cambio de motor. (https://github.com/kchala12/Grupo-4-direccional-/blob/main/Mecanica/Im%C3%A1genes%20Electr%C3%B3nica/Pruebas%20de%20velocidad.jpeg)

SEMESTRE INTEGRADOR | CÓDIGO | FI-F-001
BITÁCORA | VERSIÓN | 3

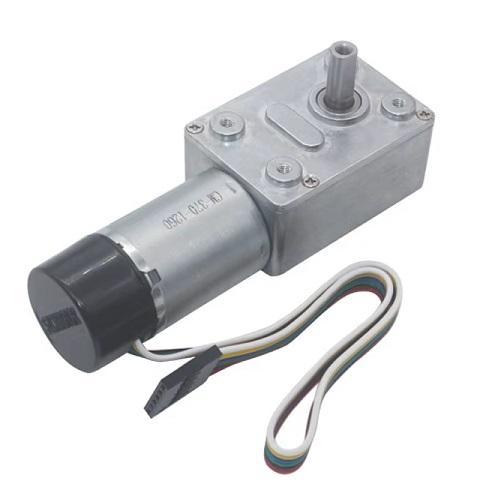
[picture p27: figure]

Encoder Quemado. (https://github.com/kchala12/Grupo-4-direccional-/blob/main/Mecanica/Im%C3%A1genes%20Electr%C3%B3nica/JGY%20370.jpg)

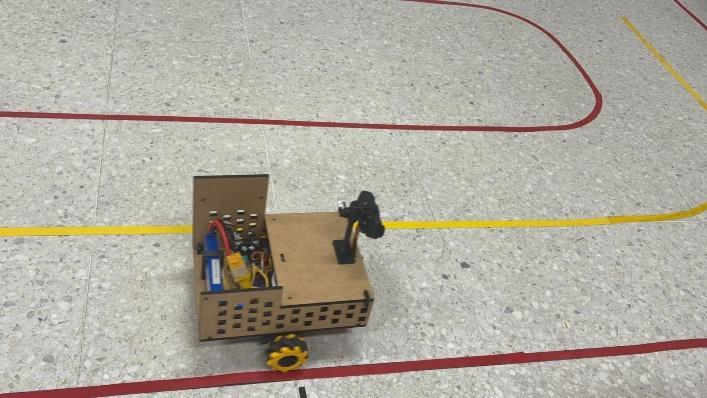
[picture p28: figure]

Prueba Antes de que se Quemara el motor. (https://github.com/kchala12/Grupo-4-direccional-/blob/main/Mecanica/Im%C3%A1genes%20Electr%C3%B3nica/Prueba%20Previa%20a%20Quemado%20de%20motor.mp4)

MATERIALES Y RECURSOS | CANT. | UNIDAD DE MEDID A | COSTO UNITARIO SIN IVA | IVA | COSTO TOTAL | JUSTIFICACIÓN
Federico Gómez Lotero | 40 | Horas | $1.400.000 | | $1.400.00 0 | Encargado de la detección de obstáculos

SEMESTRE INTEGRADOR | CÓDIGO | FI-F-001
BITÁCORA | VERSIÓN | 3
Juan Sebastián Flórez Molina | 40 | Horas | $1.400.000 | | $1.400.00 0 | Encargado de la Detección de códigos QR
Mateo Tabares Gil | 40 | Horas | $1.400.000 | | $1.400.00 0 | Encargado de la bitácora y diseño de acta
Kevin Andrés Chala Gonzalez | 40 | Horas | $1.400.000 | | $1.400.00 0 | Encargado de las pruebas electrónicas del vehículo
Tatiana Oviedo | 8 | Horas | $1.200.000 | | $1.200.00 0 | Consultas para diseño de bitácoras y actas
Carlos Andrés Rodríguez Pérez | 12 | Horas | $1.560.000 | | $1.560.00 0 | Consultas para Desarrollo de uso de la cámara
Edward Andrés Gonzalez Ríos | 12 | Horas | $2.280.000 | | $2.280.00 0 | Consultas para diseño electrónico
Motor JGY370 | 1 | und | $55.000 | $9.900 | $64.900 | Reemplazo del motor quemado
Espacio del laboratorio | 40 | Horas | $208.772 | $254.60 0 | $254.600 | Espacio para el desarrollo del proyecto
COMPROMISOS | RESPONSABLE

## FECHA DE INICIO

## FECHA FIN

## APRENDIZAJES CLAVE

## OBSERVACIONES DOCENTES

OBSERVACIÓN | FECHA | DOCENTE
Terminar efectivamente las pruebas de velocidad y el posicionamiento del autómata | Mateo Tabares | 04/05/2026 | 08/05/2026 | Implementa procedimientos de revisión eléctrica previo a la puesta en funcionamiento del vehículo.

## CONTROL DE CAMBIOS ESPACIO SOLO PARA CAMBIOS DEL FORMATO

SEMESTRE INTEGRADOR | CÓDIGO | FI-F-001
BITÁCORA | VERSIÓN | 3
RESPONSABLE DEL CAMBIO | JUSTIFICACIÓN DEL CAMBIO | DESCRIPCIÓN DEL CAMBIO | FECHA DE CAMBIO | NÚMERO DEL CAMBIO
Angie Tatiana Rengifo Oviedo | Se encontró que el formato anterior le faltaba información y era confuso para el proceso de ABP | Modificación de parámetros en la documentación de la ejecución. | 30/01/2026 | Versión 2
Angie Tatiana Rengifo Oviedo | En la ejecución de presupuesto no solo se debe tener en cuenta los materiales. Se debe tener los diferentes recursos utilizados y que se proyectaron en el acta de constitución. | Se modifica en la sección de ejecución la relación presupuestal para que sean “Materiales y Recursos”

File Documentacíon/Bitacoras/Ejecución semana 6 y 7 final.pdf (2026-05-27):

## INGENIERÍA MECATRÓNICA

SEMESTRE INTEGRADOR | CÓDIGO | FI-F-0 0 1
BITÁCORA | VERSIÓN | 2

## IDENTIFICACIÓN DEL PROYECTO

## NOMBRE DEL PROYECTO:

## INTEGRANTES DEL EQUIPO

NOMBRE | APELLIDOS | CÓDIGO | ROL EN EL PROYECTO
Federico | Gomez Lotero | 1085717866 | Diseño Mecánico
NOMBRE | APELLIDOS | CÓDIGO | ROL EN EL PROYECTO
Juan Sebastian | Flores Molina | 1081054047 | Programación
NOMBRE | APELLIDOS | CÓDIGO | ROL EN EL PROYECTO
Kevin Andres | Chala Gonzalez | 1128904330 | Documentación
NOMBRE | APELLIDOS | CÓDIGO | ROL EN EL PROYECTO
Mateo | Tabares Gil | 1087990038 | Diseño Electrónico

## FECHA DE ENTREGA (06/03/2026):

## SEMANA NO: 6 y 7 RESPONSABLE DEL REGISTRO: Kevin Andrés Chala Gonzalez

ETAPA/FASE DEL PROYECTO: Inicio de construcción del chasis del vehículo y acoples,

## Diseño de la PCB, y Arranque inicial del vehículo

## PLANEACIÓN

## OBJETIVOS (Definidos en la reunión de planeación):

## - Formalizar y estructurar la propuesta del proyecto, definiendo claramente los

alcances, materiales y metodología de trabajo.

- Iniciar el diseño del chasis del vehículo, realizando el ensamblaje básico y los acoples necesarios para su estructura principal.

## - Diseñar la tarjeta de circuito impreso (PCB) para la integración y control de los

componentes electrónicos del prototipo.

## - Realizar pruebas de arranque inicial del vehículo para verificar el correcto

funcionamiento del sistema.

## - Registrar en la bitácora los avances, dificultades encontradas y soluciones

planteadas durante el desarrollo de las actividades.

## - Evidenciar el progreso técnico del proyecto mediante descripciones

detalladas y seguimiento continuo.

## INGENIERÍA MECATRÓNICA

SEMESTRE INTEGRADOR | CÓDIGO | FI-F-00 1
BITÁCORA | VERSIÓN | 2
ACTIVIDAD | FECHA INICIO | FECHA FIN | MATERIALES | PRESUPUESTO | RIESGOS POTENCIALES | ALTERNATIVAS | ENTREGABLE | RESPON SABLE
inicio de construcción del chasis del vehículo y acoples | 23/02/26 | 03/03/26 | Fusión, computador, Impresora 3D PLA | Fusión $313.586 PLA $80.000 Impresora 3D $ 3.500.000 | Pérdida, alteración o acceso no autorizado a los archivos de diseño del chasis (modelos CAD), lo que puede generar errores en la fabricación, reprocesos o fallos en el producto final | Implementar control de versiones y copias de seguridad periódicas de los diseños, junto con restricciones de acceso únicamente al personal autorizado | Base completa | Federico Gómez
Arranque inicial del vehículo | 19/03/26 | 20/03/26 | Computador, visual studio | Visual Studio $922.314 | Pérdida o alteración del código fuente del sistema de arranque | Implementar control de versiones y acceso restringido al código | Primer código de arranque del vehículo | Juan Sebastián
Diseño de la PCB | 09/03/26 | 18/03/26 | diseño electrónico de la PCB | Fusión $313.586 | Pérdida o modificació n no controlada de los archivos de diseño de la PCB | Realizar copias de seguridad periódicas y control de versiones de los diseños | Diseño de PCB | Mateo Tabares

Registró avances del proyecto; Documento; del proyecto; Falta de; registro o pérdida de la información del progreso del proyecto; Mantener bitácoras digitales respaldadas y acceso controlado a la documentación; Bitácora actualizad a; Kevin Andrés

## EJECUCIÓN

ACTIVIDAD | FECHA INICIO | FECHA FIN | MATERIALES | PRESUPUESTO | RIESGOS POTENCIALES | Probabilidad e impacto | ALTERNATIVAS
inicio de construcción del chasis del vehículo y acoples | 09/09/2026 | 19/03/2026 | Fusión, computador, Impresora 3D y PLA | Fusión $313.586 PLA $80.000 Impresora 3D $ 3.500.000 | Pérdida, alteración o acceso no autorizado a los archivos de diseño del chasis (modelos CAD), lo que puede generar errores en la fabricación, reprocesos o fallos en el producto final | Probabilidad: Baja Impacto: Medio | Implementar mecanismos de respaldo periódico de la información, tales como copias de seguridad en la nube y en dispositivos físicos externos. Asimismo, establecer controles de acceso restringido a los archivos de diseño mediante el uso de permisos y autenticación segura.
Arranque inicial del vehículo | 19/03/2026 | 20/03/2026 | Computador, visual studio | Visual Studio $922.314 | Pérdida o alteración del código fuente del sistema de arranque | Probabilidad: Baja Impacto: Alto | Realizar copias de seguridad periódicas del código fuente en repositorios locales y en la nube. Asimismo, implementar un sistema de control de versiones (por ejemplo, Git) que permita gestionar cambios y recuperar versiones anteriores en caso de fallos.
Diseño de la PCB | 09/03/26 | 18/03/26 | Diseño electrónico de la PCB | Fusión $313.586 | Pérdida o modificación no controlada de los archivos de diseño de la PCB | Probabilidad: Baja Impacto: Alto | Establecer un sistema de control de versiones para los archivos de diseño de la PCB, así como realizar copias de seguridad frecuentes en diferentes medios de almacenamiento.
Registró avances del proyecto | 16/03/2026 | 20/03/2026 | Documento del proyecto | N/A | Falta de registro o pérdida de la información del progreso del proyecto | Probabilidad: Baja Impacto: Medio | Implementar un sistema organizado de registro y seguimiento del proyecto mediante bitácoras digitales y almacenamiento en la nube.
TOTAL | | | | $ 3.893.586

## ANÁLISIS DE CAUSA RAÍZ DESAFÍOS ENCONTRADOS:

Durante el desarrollo de la semana siete, en el marco de las pruebas realizadas, se evidenció una falla crítica asociada al

sistema de alimentación del robot. Específicamente, durante la evaluación de su autonomía, los conductores eléctricos

utilizados no soportaron la corriente requerida por el sistema, lo que ocasionó su sobrecalentamiento y posterior

deterioro.

Ante esta situación, los ingenieros Federico Gómez Lotero y Mateo Tabares Gil intervinieron de manera oportuna,

logrando mitigar el riesgo y evitar consecuencias de mayor gravedad sobre los componentes del sistema. Este incidente

puso de manifiesto la necesidad de realizar una adecuada selección de los elementos eléctricos.

De igual forma, durante la semana anterior, específicamente el lunes 16 de marzo, se identificó un defecto de fábrica en

uno de los componentes del sistema, con el apoyo del ingeniero Carlos Andrés Rodríguez. Dicho inconveniente se

evidenció tras una falla en el encapsulado del puente H, lo que provocó el deterioro del circuito integrado y su posterior

inutilización.

Como consecuencia de esta situación, el ingeniero Mateo Tabares Gil, encargado del área, se vio en la necesidad de

gestionar el reemplazo del componente.

## EVIDENCIA (FOTOGRAFÍA Y ENLACE A REPOSITORIO):

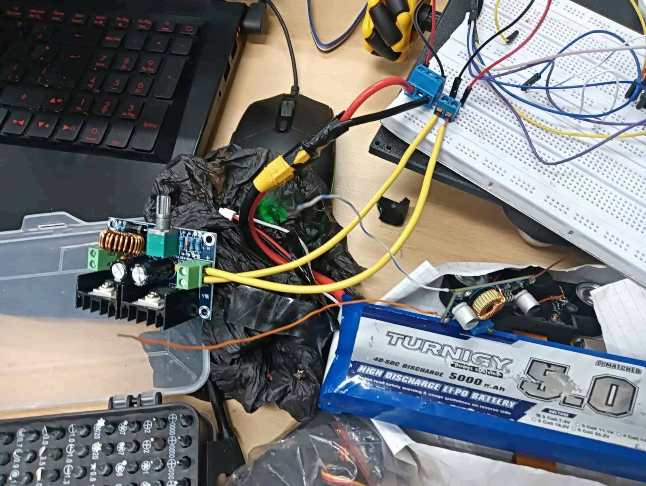
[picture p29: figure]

→
Circuito luego de la prueba (https://github.com/kchala12/Grupo-4-direccional-/blob/main/Documentac%C3%ADon/Circuito%20luego%20de%20la%20prueba.jpeg)

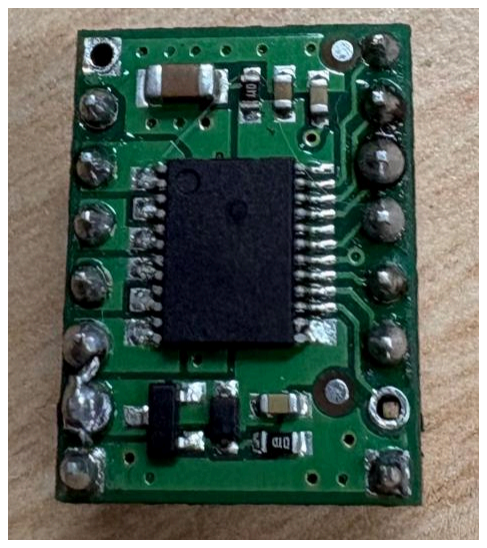
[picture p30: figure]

→Puente h defectuoso (https://github.com/kchala12/Grupo-4-direccional-/blob/main/Documentac%C3%ADon/Puente%20H%20defectuoso.jpeg)

## INGENIERÍA MECATRÓNICA

SEMESTRE INTEGRADOR | CÓDIGO | FI-F-0 0 1
BITÁCORA | VERSIÓN | 2
MATERIALES | CANT . | UNIDAD DE MEDIDA | COSTO UNITA RIO SIN IVA | IVA | COSTO TOTAL | JUSTIFICACIÓN
Filamento PLA | 300 | gr | $64.800 | $80.00 0 | $24.000 | Impresión de la base para las pruebas de conecciones, llantas y motores.
Federico Gómez Lotero | 40 | Horas | $1.400.000 | | | Encargado del diseño de base
Juan Sebastián Flórez Molina | 40 | Horas | $1.400.000 | | | Encargado de las pruebas de ruedas, motores y ayuda en el desarrollo de la programación
Mateo Tabares Gil | 40 | Horas | $1.400.000 | | | Encargado de la programación y ayuda en el desarrollo de las pruebas

Kevin Andrés Chala Gonzalez | 40 | Horas | $1.400.000 | | | Encargado de la bitácora y diseño de acta
Tatiana Oviedo | 8 | Horas | $1.200.000 | | | Consultas para diseño de bitácoras y actas
Carlos | 96 | Horas | $130.000 | | | Consultas para diseño mecánico de la base
Edward Gonzales | 96 | Horas | $190.000 | | | Consultas para diseño electrónico
Puente h tb 6612 | 1 | und | $11.500 | | | Reemplazo del anterior
Cable Vehicular Centelsa | 1 | mt | $1.800 | | | Reemplazo de los cables
Espacio del laboratorio | 40 | Horas | $208.772 | $254.6 00 | $254.600 | Espacio para el desarrollo del proyecto
COMPROMISOS | RESPONSABLE | FECHA DE INICIO
FECHA FIN | APRENDIZAJ

## ES CLAVE

## OBSERVACIONES DOCENTES

OBSERVACIÓN | FECHA | DOCENTE

## CONTROL DE CAMBIOS ESPACIO SOLO PARA CAMBIOS DEL FORMATO

## RESPONSABLE DEL CAMBIO

## JUSTIFICACIÓN DEL CAMBIO

## DESCRIPCIÓN DEL CAMBIO

## FECHA DE CAMBIO

## NÚME RO DEL CAMBI

O

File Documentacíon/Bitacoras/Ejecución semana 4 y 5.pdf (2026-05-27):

### INGENIERÍA MECATRÓNICA

SEMESTRE INTEGRADOR | CÓDIGO | FI-F-001
BITÁCORA | VERSIÓN | 2

IDENTIFICACIÓN DEL PROYECTO

NOMBRE DEL PROYECTO:

INTEGRANTES DEL EQUIPO
NOMBRE | APELLIDOS | CÓDIGO | ROL EN EL PROYECTO
Federico | Gomez Lotero | 1085717866 | Diseño Mecánico
NOMBRE | APELLIDOS | CÓDIGO | ROL EN EL PROYECTO
Juan Sebastian | Flores Molina | 1081054047 | Programación
NOMBRE | APELLIDOS | CÓDIGO | ROL EN EL PROYECTO
Kevin Andres | Chala Gonzalez | 1128904330 | Documentación
NOMBRE | APELLIDOS | CÓDIGO | ROL EN EL PROYECTO
Mateo | Tabares Gil | 1087990038 | Diseño Electrónico

FECHA DE ENTREGA (20/02/2026):

SEMANA NO: 4 y 5
RESPONSABLE DEL REGISTRO: Kevin Andres Chala Gonzalez

ETAPA/FASE DEL PROYECTO: Diseño de chasis e investigación de código para las ruedas

PLANEACIÓN

OBJETIVOS (Definidos en la reunión de planeación):

- Formalizar y estructurar la propuesta del proyecto, definiendo claramente los alcances, materiales y metodología de trabajo.
- Iniciar el diseño del chasis del vehículo, realizando el ensamblaje básico y los acoples necesarios para su estructura base.
- Investigar y analizar alternativas de programación para el control de las llantas, evaluando posibles métodos de conexión y funcionamiento.
- Registrar en la bitácora los avances, dificultades encontradas y soluciones planteadas durante el desarrollo de las actividades.
- Evidenciar el progreso técnico del proyecto mediante descripciones detalladas y seguimiento continuo.

SEMESTRE INTEGRADOR | CÓDIGO | FI-F-001
BITÁCORA | VERSIÓN | 2
ACTIVIDAD | FECHA INICIO | FECHA FIN | MATERIALES | PRESUPUESTO | RIESGOS POTENCIALES | ALTERNATIVAS | ENTREGABLE | RESPONSAB LE
Diseño mecánico de la base | 25/02/2026 | 06/03/26 | Fusión, computador. | Fusión $313.586 | Fallos en los encastres | NA | Chasis completo | Federico
Ensayo de llantas y motores del vehículo | 23/02/26 | 02/03/26 | Computador, visual studio | Visual Studio $922.314 | NA | NA | Primer código base | Juan Sebastian
Búsqueda inicial de programación de llantas | 23/02/26 | 04/03/26 | motor y llantas | Motor $37.020 llantas $16.770 | Fallos de conexión | Verificación de cableado | Motores y llantas con electronica basica | Mateo
Bitácora | 25/02/2026 | 06/03/26 | Documento del proyecto | NA | Falta de información o pruebas | NA | Bitácora actualizada | Kevin Andres

EJECUCIÓN

ACTIVIDAD | FECHA INICIO | FECHA FIN | OPORTUNIDADES DE MEJORA O DESAFÍOS ENCONTRADOS | ACCIONES CORRECTIVAS O DE MEJORA | ESTADO DE ENTREGABLE | RESPONSABLE
Diseño mecánico de la base | 23/02/26 | 03/03/26 | Dificultades con el programa fusión al momento de usarlo por primera vez | Consultar con el ingeniero Carlos sobre el programa. | 100 % | Federico Gomez
Ensayo de llantas y motores del vehículo | 27/02/26 | 06/03/26 | Al momento de usar los motores se encontró un cableado erróneo desde la fábrica. | Luego de consultar con el ingeniero carlos, se logró hallar gracias al datasheet y comparaciones las conexiones correctas | 100 % | Juan Florez
Búsqueda inicial de programación de llantas | 02/03/26 | 06/03/26 | N/A | N/A | 100 % | Mateo Tabares
Bitácora | 23/02/26 | 06/03/26 | N/A | N/A | 100 % | Kevin Chala

SEMESTRE INTEGRADOR | CÓDIGO | FI-F-001
BITÁCORA | VERSIÓN | 2

ANÁLISIS DE CAUSA RAÍZ DESAFÍOS ENCONTRADOS:

Desarrollo de control básico de motores y llantas:

Al momento de realizar las pruebas de funcionamiento de los motores, se evidenció que en varios grupos el motor JGY-370 con encoder no operaba correctamente. Tras consultar con el ingeniero Carlos, se llegó a la conclusión de que algunos motores presentaban una conexión incorrecta de fábrica.

Posteriormente, gracias a la colaboración del ingeniero Juan Sebastián Flores Molina, se logró identificar la conexión adecuada, mediante la comparación entre un motor correctamente cableado y otro que presentaba una configuración diferente.

EVIDENCIA (FOTOGRAFÍA Y ENLACE A REPOSITORIO):

→https://github.com/kchala12/Grupo-4-direccional-/blob/main/Documentacíon/base.jpeg

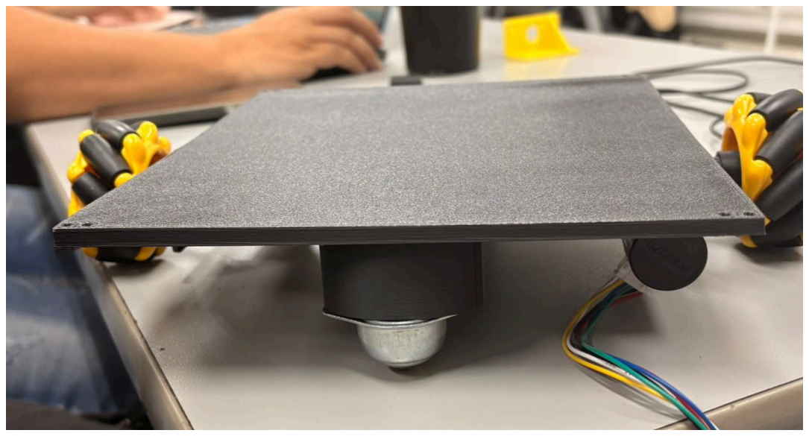
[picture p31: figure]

Base diseñada para prácticas de movimiento en PLA

→https://github.com/kchala12/Grupo-4-direccional-/blob/main/Documentacíon/Electronica.jp eg

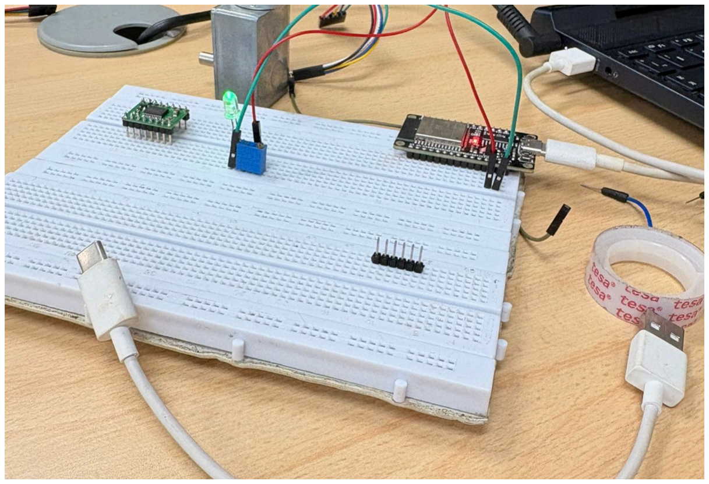
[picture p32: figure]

Montaje electrónico para prueba entre llantas y motores

SEMESTRE INTEGRADOR | CÓDIGO | FI-F-001
BITÁCORA | VERSIÓN | 2

→https://github.com/kchala12/Grupo-4-direccional-/blob/main/Documentacíon/motor%20def ectuoso.jpeg

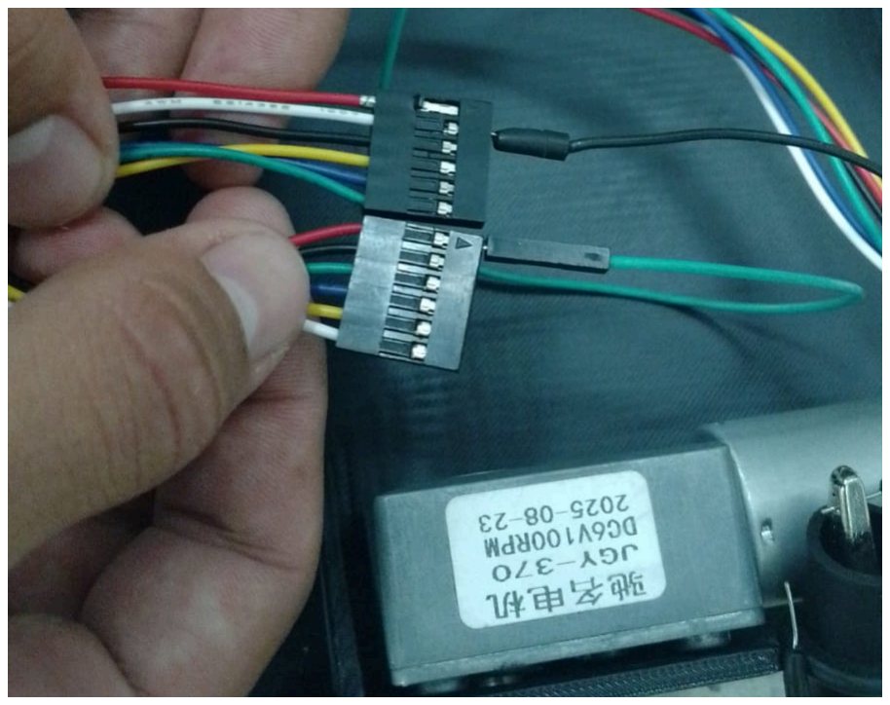
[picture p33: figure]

Comparación motor defectuoso contra un motor con buenas conexiones.

→Video de prueba del motor.

https://github.com/kchala12/Grupo-4-direccional-/blob/main/Documentacíon/motor%20funcio nal.mp4

MATERIALES | CANT. | UNIDAD DE MEDIDA | COSTO UNITARIO SIN IVA | IVA | COSTO TOTAL | JUSTIFICACIÓN
Filamento PLA | 300 | gr | $64.800 | $80.000 | $24.000 | Impresión de la base para las pruebas de conecciones, llantas y motores.
Federico Gómez Lotero | 40 | Horas | $1.400.000 | | | Encargado del diseño de base
Juan Sebastián Flórez Molina | 40 | Horas | $1.400.000 | | | Encargado de las pruebas de ruedas, motores y ayuda en el desarrollo de la programación
Mateo Tabares Gil | 40 | Horas | $1.400.000 | | | Encargado de la programación y ayuda en el desarrollo de las pruebas
Kevin Andrés Chala Gonzalez | 40 | Horas | $1.400.000 | | | Encargado de la bitácora y diseño de acta
Tatiana Oviedo | 8 | Horas | $1.200.000 | | | Consultas para diseño de bitácoras y actas

SEMESTRE INTEGRADOR | CÓDIGO | FI-F-001
BITÁCORA | VERSIÓN | 2
Carlos | 96 | Horas | $130.000 | | | Consultas para diseño mecánico de la base
Edward Gonzales | 96 | Horas | $190.000 | | | Consultas para diseño electrónico
Espacio del laboratorio | 40 | Horas | $208.772 | $254.600 | $254.600 | Espacio para el desarrollo del proyecto
COMPROMISOS | RESPONSABLE

FECHA DE
INICIO

FECHA FIN
APRENDIZAJES CLAVE

OBSERVACIONES DOCENTES

OBSERVACIÓN | FECHA | DOCENTE

CONTROL DE CAMBIOS
ESPACIO SOLO PARA CAMBIOS DEL FORMATO

RESPONSABLE DEL
CAMBIO

JUSTIFICACIÓN DEL CAMBIO
DESCRIPCIÓN DEL
CAMBIO

FECHA DE
CAMBIO

NÚMERO
DEL
CAMBIO

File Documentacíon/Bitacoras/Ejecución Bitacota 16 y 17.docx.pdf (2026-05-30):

### INGENIERÍA MECATRÓNICA

SEMESTRE INTEGRADOR | CÓDIGO | FI-F-001
BITÁCORA | VERSIÓN | 3

IDENTIFICACIÓN DEL PROYECTO

NOMBRE DEL PROYECTO: C.A.L.V.O.S

INTEGRANTES DEL EQUIPO
NOMBRE | APELLIDOS | CÓDIGO | ROL EN EL PROYECTO
Federico | Gomez Lotero | 1085717866 | Diseño Mecánico
NOMBRE | APELLIDOS | CÓDIGO | ROL EN EL PROYECTO
Juan Sebastian | Flores Molina | 1081054047 | Programación
NOMBRE | APELLIDOS | CÓDIGO | ROL EN EL PROYECTO
Kevin Andres | Chala Gonzalez | 1128904330 | Documentación
NOMBRE | APELLIDOS | CÓDIGO | ROL EN EL PROYECTO
Mateo | Tabares Gil | 1087990038 | Diseño Electrónico

FECHA DE ENTREGA : (15/05/2026)

SEMANA NO: 16 y 17

RESPONSABLE DEL REGISTRO: Federico Gomez

ETAPA/FASE DEL PROYECTO: Documentación y ajuste

PLANEACIÓN

OBJETIVOS (Definidos en la reunión de planeación):

1. Para la presente semana se tiene programado avanzar en los ajustes finales de posicionamiento y calibración del sistema, así como realizar la presentación de los resultados obtenidos durante el desarrollo del proyecto.
ACTIVIDAD | FECHA INICIO | FECHA FIN | MATERIALES | PRESUPUESTO | RIESGOS POTENCIALES | ALTERNATIVAS | ENTREGABLE | RESPONSABLE
Entrega final del vehiculo | 25/05/202 6 | 25/05/202 6 | Computado r, documento s de google | N/A | Pérdida de información, registros incompletos | Copias de seguridad, uso de herramientas digitales de respaldo | Registro documenta do de actividades realizadas | Mateo tabares
Ajustes menores de | 18/05/202 6 | 22/05/202 6 | Computado r, documento s | N/A | Pérdida de información, registros | Copias de seguridad, uso de | Registro documenta do de | Federico gomez

SEMESTRE INTEGRADOR | CÓDIGO | FI-F-001
BITÁCORA | VERSIÓN | 3
codigo | | | de google | | incompletos | herramientas digitales de respaldo | actividades realizadas
Bitácora | 20/05/2 026 | 15/05/26 | Computado r, documento s de google | N/A | Registros incomple tos y falta de actualizac ión constante de la información. | Implementar formato estándar y asignar responsable para el diligenciamie nto | documenta do de actividades realizadas | Juan Flórez

EJECUCIÓN

ACTIVIDAD | FECHA INICIO | FECHA FIN | OPORTUNIDADES DE MEJORA O DESAFÍOS ENCONTRADOS | ACCIONES CORRECTIVAS O DE MEJORA | ESTADO DE ENTREGABLE | RESPONSABLE
Entrega final del vehiculo | 25/05/2026 | 25/05/2026 | Se evidenció retraso en la validación final del sistema eléctrico y ajustes estéticos pendientes. | Se implementó una revisión técnica previa a la entrega y se asignó tiempo adicional para pruebas funcionales. | 100% | Mateo Tabares
Ajustes menores de codigo | 18/05/2026 | 22/05/2026 | Se encontraron errores en la comunicación entre sensores y microcontrolador. | Se optimizó el código de lectura de sensores y se realizaron pruebas unitarias para validar estabilidad. | 100% | Federico gomez
Bitácora | 20/05/2026 | 15/05/26 | Se logró mantener un registro organizado y detallado de las actividades desarrolladas durante el proyecto. | Se implementó una actualización periódica de la información y evidencias para mejorar la trazabilidad del proceso. | 100% | Juan Flórez

ANÁLISIS DE CAUSA RAÍZ DESAFÍOS ENCONTRADOS:

Durante la semana de desarrollo del proyecto, uno de los principales desafíos identificados fue el proceso de adaptación e integración del código de programación del robot autónomo, debido a la necesidad de optimizar la comunicación y funcionamiento entre los diferentes componentes electrónicos y de control. Este proceso demandó múltiples pruebas, ajustes y validaciones para garantizar un desempeño estable y eficiente del sistema.

SEMESTRE INTEGRADOR | CÓDIGO | FI-F-001
BITÁCORA | VERSIÓN | 3

Como acción de mejora, se realizó una revisión detallada de la estructura del código, permitiendo optimizar su funcionamiento y lograr una correcta adaptación a los requerimientos del proyecto. Adicionalmente, se implementaron mejoras estéticas en el robot autónomo, enfocadas en fortalecer su presentación visual, organización estructural y acabado final, obteniendo así un resultado más profesional y funcional.

- Durante el proceso de implementación y validación de las modificaciones realizadas al sistema, se identificaron diversas inconsistencias operativas asociadas a las estaciones de carga y descarga, las cuales afectan el correcto funcionamiento de los vehículos autónomos de todos los equipos participantes. Entre las principales dificultades encontradas se evidenciaron problemas de posicionamiento, diferencias en las dimensiones funcionales de las estaciones y variaciones en las condiciones de detección utilizadas por los sistemas de navegación.

### Análisis de Causa Raíz – Metodología de los 7 Porqués

- Problema identificado: Las estaciones de carga y descarga presentaban errores que afectan el funcionamiento de los vehículos autónomos.
- ¿Por qué?
Porque los vehículos presentaban dificultades al interactuar correctamente con las estaciones de carga y descarga durante las pruebas de funcionamiento.
- ¿Por qué?
Porque existían diferencias en las condiciones físicas, dimensiones y parámetros operativos de las estaciones implementadas por los distintos equipos de trabajo.
- ¿Por qué?
Porque no se realizó una validación integral de compatibilidad entre las estaciones y los sistemas de navegación antes de la fase final de pruebas.
- ¿Por qué?
Porque las verificaciones efectuadas se concentraron principalmente en pruebas individuales de cada subsistema y no en pruebas de integración global.
- ¿Por qué?
Porque cada equipo desarrolló y ajustó sus componentes de manera independiente durante gran parte del proceso de construcción.
- ¿Por qué?
Porque no se estableció desde las etapas iniciales un cronograma periódico de pruebas colaborativas e integración entre todos los grupos participantes.
- ¿Por qué?
Porque se asumió que el cumplimiento de las especificaciones de diseño sería suficiente para garantizar la compatibilidad entre los diferentes subsistemas del proyecto.

SEMESTRE INTEGRADOR | CÓDIGO | FI-F-001
BITÁCORA | VERSIÓN | 3

EVIDENCIA (FOTOGRAFÍA Y ENLACE A REPOSITORIO):

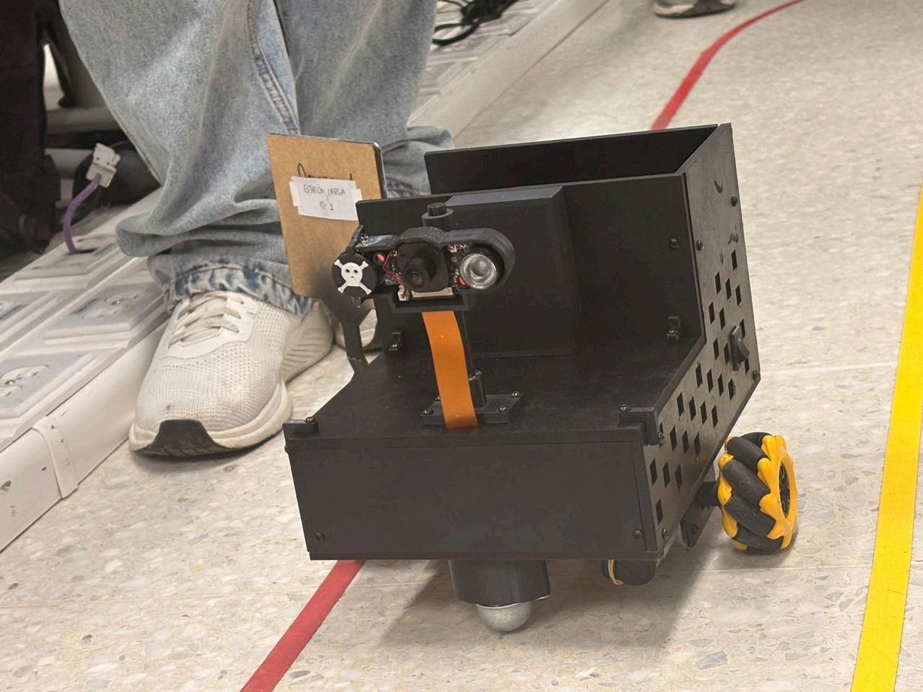
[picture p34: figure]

Robot con modificación estética (https://github.com/kchala12/Grupo-4-direccional-/blob/main/Electronica/Im%C3%A1genes%20Electr%C3%B3nica/Imagen%20estetica%20del%20robot.jpeg)

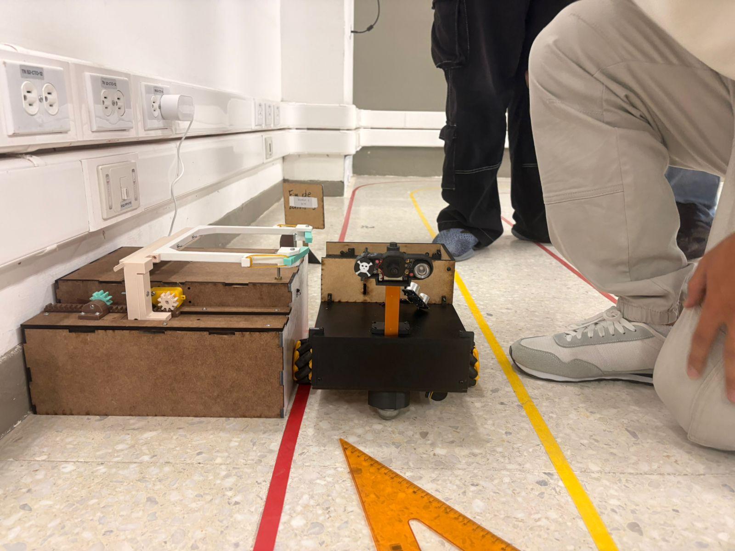
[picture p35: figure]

Zonas de descarga con defectos (https://github.com/kchala12/Grupo-4-direccional-/blob/main/Electronica/Im%C3%A1genes%20Electr%C3%B3nica/Nuevas%20pruebas%20en%20zonas%20de%20descargue%20.jpeg)

SEMESTRE INTEGRADOR | CÓDIGO | FI-F-001
BITÁCORA | VERSIÓN | 3
MATERIALES Y RECURSOS | CANT. | UNIDAD DE MEDID A | COSTO UNITARIO SIN IVA | IVA | COSTO TOTAL | JUSTIFICACIÓN
Federico Gómez Lotero | 40 | Horas | $1.400.000 | | $1.400.00 0 | Encargado de la detección de obstáculos
Juan Sebastián Flórez Molina | 40 | Horas | $1.400.000 | | $1.400.00 0 | Encargado de la Detección de códigos QR
Mateo Tabares Gil | 40 | Horas | $1.400.000 | | $1.400.00 0 | Encargado de la bitácora y diseño de acta
Kevin Andrés Chala Gonzalez | 40 | Horas | $1.400.000 | | $1.400.00 0 | Encargado de las pruebas electrónicas del vehículo
Tatiana Oviedo | 8 | Horas | $1.200.000 | | $1.200.00 0 | Consultas para diseño de bitácoras y actas
Carlos Andrés Rodríguez Pérez | 12 | Horas | $1.560.000 | | $1.560.00 0 | Consultas para Desarrollo de uso de la cámara
Edward Andrés Gonzalez Ríos | 12 | Horas | $2.280.000 | | $2.280.00 0 | Consultas para diseño electrónico
Espacio del laboratorio | 40 | Horas | $208.772 | $254.60 0 | $254.600 | Espacio para el desarrollo del proyecto
COMPROMISOS | RESPONSABLE | FECHA DE INICIO | FECHA FIN | APRENDIZAJES CLAVE
Realizar la corrección y estandarización de las estaciones de carga y descarga para garantizar la compatibilidad con los vehículos autónomos. | Todos los equipos de trabajo e ingenieros responsables del proyecto. | 29/05/2026 | 01/06/2026 | La validación temprana y las pruebas de integración entre equipos son fundamentales para detectar incompatibilida des antes de las etapas finales del proyecto.

SEMESTRE INTEGRADOR | CÓDIGO | FI-F-001
BITÁCORA | VERSIÓN | 3

OBSERVACIONES DOCENTES

OBSERVACIÓN | FECHA | DOCENTE

CONTROL DE CAMBIOS
ESPACIO SOLO PARA CAMBIOS DEL FORMATO
RESPONSABLE DEL CAMBIO | JUSTIFICACIÓN DEL CAMBIO | DESCRIPCIÓN DEL CAMBIO | FECHA DE CAMBIO | NÚMERO DEL CAMBIO
Angie Tatiana Rengifo Oviedo | Se encontró que el formato anterior le faltaba información y era confuso para el proceso de ABP | Modificación de parámetros en la documentación de la ejecución. | 30/01/2026 | Versión 2
Angie Tatiana Rengifo Oviedo | En la ejecución de presupuesto no solo se debe tener en cuenta los materiales. Se debe tener los diferentes recursos utilizados y que se proyectaron en el acta de constitución. | Se modifica en la sección de ejecución la relación presupuestal para que sean “Materiales y Recursos”

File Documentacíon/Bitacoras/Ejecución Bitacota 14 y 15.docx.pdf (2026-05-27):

### INGENIERÍA MECATRÓNICA

SEMESTRE INTEGRADOR | CÓDIGO | FI-F-001
BITÁCORA | VERSIÓN | 3

IDENTIFICACIÓN DEL PROYECTO

NOMBRE DEL PROYECTO: C.A.L.V.O.S

INTEGRANTES DEL EQUIPO
NOMBRE | APELLIDOS | CÓDIGO | ROL EN EL PROYECTO
Federico | Gomez Lotero | 1085717866 | Diseño Mecánico
NOMBRE | APELLIDOS | CÓDIGO | ROL EN EL PROYECTO
Juan Sebastian | Flores Molina | 1081054047 | Programación
NOMBRE | APELLIDOS | CÓDIGO | ROL EN EL PROYECTO
Kevin Andres | Chala Gonzalez | 1128904330 | Documentación
NOMBRE | APELLIDOS | CÓDIGO | ROL EN EL PROYECTO
Mateo | Tabares Gil | 1087990038 | Diseño Electrónico

FECHA DE ENTREGA (DD/MM/AA):

SEMANA NO: 14 y 15
RESPONSABLE DEL REGISTRO: Federico Gomez

ETAPA/FASE DEL PROYECTO: Documentación

PLANEACIÓN

OBJETIVOS (Definidos en la reunión de planeación):

1. Evaluar el desempeño del sistema mediante pruebas de velocidad, con el fin de identificar posibles mejoras en la eficiencia y tiempos de respuesta del proceso.
2. Verificar la funcionalidad y precisión del posicionamiento, asegurando que las operaciones de carga y descarga se realicen de manera segura y sin errores.
3. Analizar los resultados obtenidos en las pruebas realizadas, para proponer ajustes técnicos que mejoren el rendimiento general del sistema.
4. Desarrollar un manual de usuario completo y estructurado, que describa de manera clara el funcionamiento, uso y mantenimiento básico del sistema, facilitando su correcta operación por parte del usuario final.

SEMESTRE INTEGRADOR | CÓDIGO | FI-F-001
BITÁCORA | VERSIÓN | 3
5. Garantizar la comprensión y aplicabilidad del manual, mediante la validación del contenido con el equipo técnico y la incorporación de instrucciones.
ACTIVIDAD | FECHA INICIO | FECHA FIN | MATERIALES | PRESUPUESTO | RIESGOS POTENCIALES | ALTERNATIVAS | ENTREGABLE | RESPONSABLE
Entrega de manual de usuario | 04/05/202 6 | 08/05/202 6 | Computador | N/A | Errores en la documen tación, informaci ón incompleta, retrasos en la entrega. | Revisión por pares, uso de plantillas estandarizada s , validación con el equipo técnico. | Medio | Manual de usuario final validado y documentado
Posiciona miento para carga y descarga | 04/05/202 6 | 08/05/202 6 | Computador , GITHUB | N/A | Error en alineación del sistema, fallos en la calibración , retrasos operativos | Recalibración del sistema, pruebas manuales, ajuste de parámetros | Medio | Sistema de posiciona mien to funcional y validado
Pruebas de velocida d | 04/05/202 6 | 08/05/202 6 | Computador , GITHUB | N/A | Datos inconsistentes , fallos en medición, errores de ejecución | Repetición de pruebas, uso de herramientas de medición adicionales | Medio | Reporte de resultados de pruebas de velocidad

EJECUCIÓN

ACTIVIDAD | FECHA INICIO | FECHA FIN | OPORTUNIDADES DE MEJORA O DESAFÍOS ENCONTRADOS | ACCIONES CORRECTIVAS O DE MEJORA | ESTADO DE ENTREGABLE | RESPONSABLE
Entrega de manual de usuario | 04/05/2026 | en proceso | Ajustes de formato y validación de contenido técnico del manual. | Corrección de redacción y actualización de información técnica del sistema. . | En proceso | Juan Florez
Posicionami ento para carga y descarga | 04/05/2026 | 08/05/2026 | Desviaciones leves en el posicionamiento del robot durante la llegada a las estaciones. | Ajuste de lectura de códigos QR y calibración de trayectoria. | Finalizado | Mateo Tabares

SEMESTRE INTEGRADOR | CÓDIGO | FI-F-001
BITÁCORA | VERSIÓN | 3

Pruebas de
velocidad

Bitácora

04/05/2026

20/04/2026

08/05/2026

15/05/26

Variaciones de
velocidad en
curvas y pérdida
de estabilidad en
algunos
recorridos.

Registros
incompletos y
falta de
actualización
constante de la
información.

Ajuste de
parámetros
PWM y
optimización
del
control de
motores.

Implementar
formato
estándar y
asignar
responsable
para el
diligenciamient
o
diario.

Finalizado

Terminado

Kevin Chala

Federico Gomez

ANÁLISIS DE CAUSA RAÍZ DESAFÍOS ENCONTRADOS:

Debido a la ampliación del tiempo establecido para la entrega del manual de usuario del proyecto y gracias a las observaciones realizadas por la ingeniera Tatiana Oviedo, se tomó la decisión de realizar una corrección y restructuración completa del manual de usuario, con el fin de mejorar su contenido técnico, organización y calidad documental.

### Problema identificado:

Fue necesario realizar una corrección y reestructuración completa del manual de usuario del proyecto.

- ¿Por qué fue necesario corregir completamente el manual de usuario?
- - Porque el documento presentaba observaciones relacionadas con la estructura, redacción y contenido técnico.
- ¿Por qué el manual presentaba deficiencias en su contenido y estructura?
- - Porque durante su elaboración no se siguió completamente una guía técnica dada por la ingeniera Tatiana.
- ¿Por qué no se utilizó una guía técnica estandarizada desde el inicio?
- - Porque el equipo prioriza el desarrollo funcional del robot sobre la documentación técnica del proyecto.
- ¿Por qué se prioriza el desarrollo funcional sobre la documentación?
- - Porque gran parte del tiempo y recursos disponibles fueron destinados a pruebas, programación y ajustes del sistema autónomo.

SEMESTRE INTEGRADOR | CÓDIGO | FI-F-001
BITÁCORA | VERSIÓN | 3
- ¿Por qué las actividades técnicas consumieron la mayor parte del tiempo del

proyecto? - Porque surgieron desafíos durante los diferentes códigos y

posicionamientos del vehículo ¿Por qué los desafíos técnicos afectaron la

planificación documental?

- - Porque no se estableció una planificación específica para revisión
y actualización progresiva de la documentación durante el
desarrollo del proyecto.
- ¿Por qué no se implementó una planificación documental adecuada desde el inicio?
- - Porque inicialmente no se contempló la importancia de mantener una documentación técnica paralela al avance del desarrollo del sistema.

EVIDENCIA (FOTOGRAFÍA Y ENLACE A REPOSITORIO):

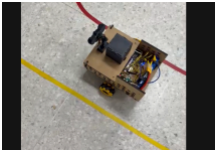
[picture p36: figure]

- Ajustes de posicionamiento

SEMESTRE INTEGRADOR | CÓDIGO | FI-F-001
BITÁCORA | VERSIÓN | 3

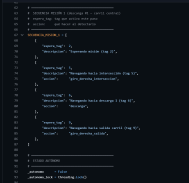
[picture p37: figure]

- Ajustes al codigo
MATERIALES Y RECURSOS | CANT. | UNIDAD DE MEDID A | COSTO UNITARIO SIN IVA | IVA | COSTO TOTAL | JUSTIFICACIÓN
Federico Gómez Lotero | 40 | Horas | $1.400.000 | | $1.400.00 0 | Encargado de la detección de obstáculos
Juan Sebastián Flórez Molina | 40 | Horas | $1.400.000 | | $1.400.00 0 | Encargado de la Detección de códigos QR
Mateo Tabares Gil | 40 | Horas | $1.400.000 | | $1.400.00 0 | Encargado de la bitácora y diseño de acta
Kevin Andrés Chala Gonzalez | 40 | Horas | $1.400.000 | | $1.400.00 0 | Encargado de las pruebas electrónicas del vehículo
Tatiana Oviedo | 8 | Horas | $1.200.000 | | $1.200.00 0 | Consultas para diseño de bitácoras y actas
Carlos Andrés Rodríguez Pérez | 12 | Horas | $1.560.000 | | $1.560.00 0 | Consultas para Desarrollo de uso de la cámara
Edward Andrés Gonzalez Ríos | 12 | Horas | $2.280.000 | | $2.280.00 0 | Consultas para diseño electrónico
Espacio del laboratorio | 40 | Horas | $208.772 | $254.60 0 | $254.600 | Espacio para el desarrollo del proyecto

SEMESTRE INTEGRADOR | CÓDIGO | FI-F-001
BITÁCORA | VERSIÓN | 3
COMPROMISOS | RESPONSABLE

FECHA DE
INICIO

FECHA FIN

APRENDIZAJES
CLAVE

OBSERVACIONES DOCENTES

OBSERVACIÓN | FECHA | DOCENTE

CONTROL DE CAMBIOS
ESPACIO SOLO PARA CAMBIOS DEL FORMATO
RESPONSABLE DEL CAMBIO | JUSTIFICACIÓN DEL CAMBIO | DESCRIPCIÓN DEL CAMBIO | FECHA DE CAMBIO | NÚMERO DEL CAMBIO
Angie Tatiana Rengifo Oviedo | Se encontró que el formato anterior le faltaba información y era confuso para el proceso de ABP | Modificación de parámetros en la documentación de la ejecución. | 30/01/2026 | Versión 2
Angie Tatiana Rengifo Oviedo | En la ejecución de presupuesto no solo se debe tener en cuenta los materiales. Se debe tener los diferentes recursos utilizados y que se proyectaron en el acta de constitución. | Se modifica en la sección de ejecución la relación presupuestal para que sean “Materiales y Recursos”

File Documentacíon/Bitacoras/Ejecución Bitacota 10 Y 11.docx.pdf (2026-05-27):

### INGENIERÍA MECATRÓNICA

SEMESTRE INTEGRADOR | CÓDIGO | FI-F-001
BITÁCORA | VERSIÓN | 3

IDENTIFICACIÓN DEL PROYECTO

NOMBRE DEL PROYECTO: C.A.L.V.O.S

INTEGRANTES DEL EQUIPO
NOMBRE | APELLIDOS | CÓDIGO | ROL EN EL PROYECTO
Federico | Gomez Lotero | 1085717866 | Diseño Mecánico
NOMBRE | APELLIDOS | CÓDIGO | ROL EN EL PROYECTO
Juan Sebastian | Flores Molina | 1081054047 | Programación
NOMBRE | APELLIDOS | CÓDIGO | ROL EN EL PROYECTO
Kevin Andres | Chala Gonzalez | 1128904330 | Documentación
NOMBRE | APELLIDOS | CÓDIGO | ROL EN EL PROYECTO
Mateo | Tabares Gil | 1087990038 | Diseño Electrónico

FECHA DE ENTREGA (DD/MM/AA):

SEMANA NO: 10 Y 11
RESPONSABLE DEL REGISTRO: Federico Gomez

ETAPA/FASE DEL PROYECTO: Autonomía Básica

PLANEACIÓN

OBJETIVOS (Definidos en la reunión de planeación):

1. Terminar el desarrollo e implementar un sistema eficiente de detección y decodificación de códigos QR, que permita al vehículo responder correctamente a los comandos recibidos.
2. Optimizar el desempeño del sistema de lectura de códigos QR, minimizando errores de decodificación mediante pruebas en diferentes condiciones de iluminación y entorno.
3. Garantizar el registro organizado y continuo de los avances del proyecto, mediante la elaboración y actualización periódica de la bitácora.
4. Asegurar la integridad y disponibilidad de la información del proyecto, implementando
mecanismos de respaldo que eviten la pérdida de datos y faciliten su seguimiento.
ACTIVIDAD | FECHA INICIO | FECHA FIN | MATERIALES | PRESUPUESTO | RIESGOS POTENCIALES | ALTERNATIVAS | ENTREGABLE | RESPONSABLE
Detección de códigos QR | 26/03/26 | 10/04/26 | Computador, visual studio | Motor $37.020 llantas $16.770 | Errores en la decodificació n de los códigos recibidos. | Realizar pruebas en ambientes con poca luz para reducir interferencias. | Prueba documentada del vehículo respondiendo a comandos QR. | Juan Flórez, Kevin Chala

SEMESTRE INTEGRADOR | CÓDIGO | FI-F-001
BITÁCORA | VERSIÓN | 3

Bitácora; Documento del proyecto; Registros incompletos por falta de tiempo o seguimiento.; Guardar respaldos en la nube para evitar pérdida de información.; actualizada; Federico; Gómez, Mateo Tabares

EJECUCIÓN

ACTIVIDAD | FECHA INICIO | FECHA FIN | OPORTUNIDADES DE MEJORA O DESAFÍOS ENCONTRADOS | ACCIONES CORRECTIVAS O DE MEJORA | ESTADO DE ENTREGABLE | RESPONSABLE
Detección de códigos QR | 26/03/26 | 03/04/26 | Dificultad en la lectura bajo diferentes condiciones de iluminación, errores en reconocimiento | . Ajuste de parámetros de detección, mejora en iluminación y calibración del sistema | Finalizado | Juan Flórez, Kevin Chala
Pruebas de velocidad | 15/04/2026 | En progreso | Variabilidad en los tiempos de respuesta, posibles cuellos de botella en el sistema | Optimización del código, repetición de pruebas y análisis de rendimiento | En progreso | Grupo en General
Bitácora | 06/04/2026 | 17/04/26 | Falta de consistencia en algunos registros, omisión de detalles relevantes | Estandarización del formato de registro y revisión periódica de la información | Finalizado | Federico Gómez, Mateo Tabares

ANÁLISIS DE CAUSA RAÍZ DESAFÍOS ENCONTRADOS:

No se hacen anotaciones

EVIDENCIA (FOTOGRAFÍA Y ENLACE A REPOSITORIO):

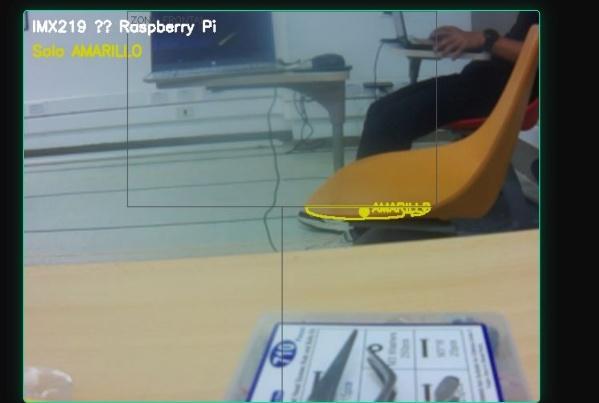
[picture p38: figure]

Ajustes de camara (https://github.com/kchala12/Grupo-4-direccional-/blob/main/Mecanica/Im%C3%A1genes%20Electr%C3%B3nica/Correcciones%20de%20imagen%20camara.jpeg)

SEMESTRE INTEGRADOR | CÓDIGO | FI-F-001
BITÁCORA | VERSIÓN | 3

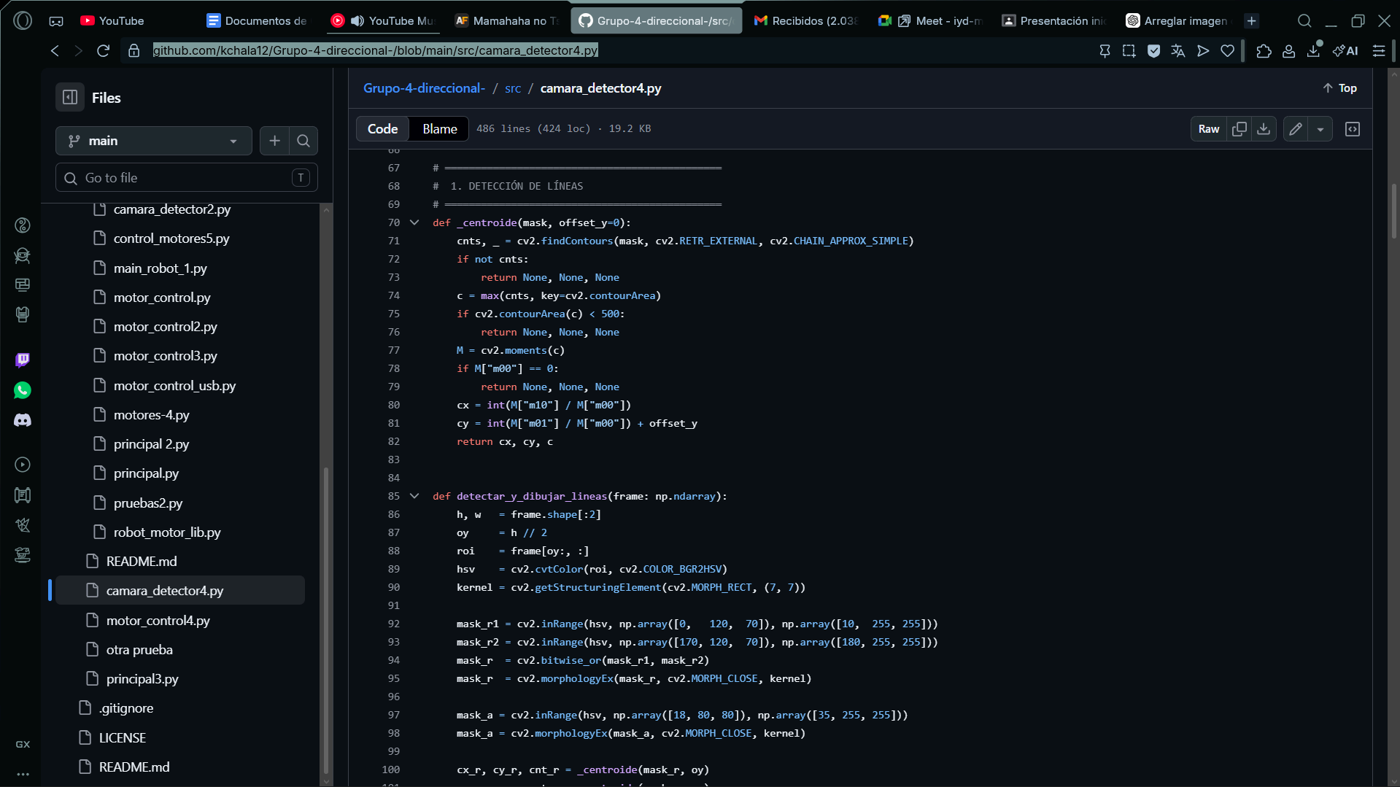
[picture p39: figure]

Código de detección de cámara (https://github.com/kchala12/Grupo-4-direccional-/blob/main/src/camara_detector4.py)

MATERIALES Y RECURSOS | CANT. | UNIDAD DE MEDID A | COSTO UNITARIO SIN IVA | IVA | COSTO TOTAL | JUSTIFICACIÓN
Federico Gómez Lotero | 40 | Horas | $1.400.000 | | $1.400.00 0 | Encargado de la detección de obstáculos
Juan Sebastián Flórez Molina | 40 | Horas | $1.400.000 | | $1.400.00 0 | Encargado de la Detección de códigos QR
Mateo Tabares Gil | 40 | Horas | $1.400.000 | | $1.400.00 0 | Encargado de la bitácora y diseño de acta
Kevin Andrés Chala Gonzalez | 40 | Horas | $1.400.000 | | $1.400.00 0 | Encargado de las pruebas electrónicas del vehículo
Tatiana Oviedo | 8 | Horas | $1.200.000 | | $1.200.00 0 | Consultas para diseño de bitácoras y actas
Carlos Andrés Rodríguez Pérez | 12 | Horas | $1.560.000 | | $1.560.00 0 | Consultas para Desarrollo de uso de la cámara
Edward Andrés Gonzalez Ríos | 12 | Horas | $2.280.000 | | $2.280.00 0 | Consultas para diseño electrónico
Espacio del laboratorio | 40 | Horas | $208.772 | $254.60 0 | $254.600 | Espacio para el desarrollo del proyecto

SEMESTRE INTEGRADOR | CÓDIGO | FI-F-001
BITÁCORA | VERSIÓN | 3
COMPROMISOS | RESPONSABLE

FECHA DE
INICIO

FECHA FIN

APRENDIZAJES
CLAVE

OBSERVACIONES DOCENTES

OBSERVACIÓN | FECHA | DOCENTE

CONTROL DE CAMBIOS
ESPACIO SOLO PARA CAMBIOS DEL FORMATO
RESPONSABLE DEL CAMBIO | JUSTIFICACIÓN DEL CAMBIO | DESCRIPCIÓN DEL CAMBIO | FECHA DE CAMBIO | NÚMERO DEL CAMBIO
Angie Tatiana Rengifo Oviedo | Se encontró que el formato anterior le faltaba información y era confuso para el proceso de ABP | Modificación de parámetros en la documentación de la ejecución. | 30/01/2026 | Versión 2
Angie Tatiana Rengifo Oviedo | En la ejecución de presupuesto no solo se debe tener en cuenta los materiales. Se debe tener los diferentes recursos utilizados y que se proyectaron en el acta de constitución. | Se modifica en la sección de ejecución la relación presupuestal para que sean “Materiales y Recursos”

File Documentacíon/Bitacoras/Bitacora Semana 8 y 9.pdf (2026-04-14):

## INGENIERÍA MECATRÓNICA

SEMESTRE INTEGRADOR | CÓDIGO | FI-F-001
BITÁCORA | VERSIÓN | 2

## IDENTIFICACIÓN DEL PROYECTO

## NOMBRE DEL PROYECTO:

## INTEGRANTES DEL EQUIPO

NOMBRE | APELLIDOS | CÓDIGO | ROL EN EL PROYECTO
Federico | Gomez Lotero | 1085717866 | Diseño Mecánico
NOMBRE | APELLIDOS | CÓDIGO | ROL EN EL PROYECTO
Juan Sebastian | Flores Molina | 1081054047 | Programación
NOMBRE | APELLIDOS | CÓDIGO | ROL EN EL PROYECTO
Kevin Andres | Chala Gonzalez | 1128904330 | Documentación
NOMBRE | APELLIDOS | CÓDIGO | ROL EN EL PROYECTO
Mateo | Tabares Gil | 1087990038 | Diseño Electrónico

## FECHA DE ENTREGA (20/02/2026):

## SEMANA NO: 8 y 9 RESPONSABLE DEL REGISTRO: Mateo Tabares

## ETAPA/FASE DEL PROYECTO: Autonomía Básica

## PLANEACIÓN

## OBJETIVOS (Definidos en la reunión de planeación):

- Realizar las pruebas electrónicas del vehículo, verificando el correcto funcionamiento de los sistemas y componentes instalados.

## - Implementar el sistema de detección de obstáculos, evaluando su precisión y respuesta

ante diferentes escenarios de prueba.

## - Investigar y aplicar la detección de códigos QR como método de control y comunicación

del vehículo, analizando su integración con los demás sistemas.

## - Registrar en la bitácora los avances, dificultades encontradas y soluciones planteadas

durante el desarrollo de las actividades.

SEMESTRE INTEGRADOR | CÓDIGO | FI-F-001
BITÁCORA | VERSIÓN | 2
ACTIVIDAD | FECHA INICIO | FECHA FIN | MATERIALES | PRESUPUESTO | RIESGOS POTENCIALES | ALTERNATIVAS | ENTREGABLE | RESPONSABLE
Inicio de pruebas electrónicas del vehículo | 25/03/2026 | 27/03/20 26 | Multímetro, computador | Fusión $313.586 | Sobrecarga de voltaje que dañe los componentes electrónicos. | Probar cada módulo de forma individual antes de integrarlos. | N/A | Kevin Chala
Inicio de detección de obstáculos | 26/03/26 | 03/04/20 26 | Computador, visual studio | Visual Studio $922.314 | El sensor no detecta correctamente los obstáculos a ciertas distancias. | Calibrar el sensor a diferentes distancias antes de las pruebas finales. | Código funcional del sistema de detección de obstáculos. | Federico Gómez
Detección de códigos QR | 26/03/26 | 03/04/26 | Computador, visual estudio | Motor $37.020 llantas $16.770 | Errores en la decodificación de los códigos recibidos. | Realizar pruebas en ambientes con poca luz para reducir interferencias. | Prueba documentada del vehículo respondiendo a comandos QR. | Juan Flores
Bitácora | 30/02/2026 | 06/03/26 | Documento del proyecto | NA | Registros incompletos por falta de tiempo o seguimiento. | Guardar respaldos en la nube para evitar pérdida de información. | Bitácora actualizada | Mateo Tabares

## EJECUCIÓN

ACTIVIDAD | FECHA INICIO | FECHA FIN | OPORTUNIDADES DE MEJORA O DESAFÍOS ENCONTRADOS | ACCIONES CORRECTIVAS O DE MEJORA | ESTADO DE ENTREGABLE | RESPONSABLE
Inicio de pruebas electrónicas del vehículo | 25/03/2026 | 27/03/2026 | Riesgo de sobrecarga de voltaje que dañe componentes electrónicos | Probar cada módulo de forma individual antes de integrarlos | 90 % | Kevin Chala
Inicio de detección de obstáculos | 26/03/26 | 03/04/2026 | El sensor no detecta correctamente los obstáculos a ciertas distancias | Calibrar el sensor a diferentes distancias antes de las pruebas finales | 100 % | Federico Gómez
Detección de códigos QR | 26/03/26 | 03/04/26 | Errores en la detección de los códigos recibidos | Realizar pruebas en ambientes con poca luz para reducir interferencias | 50 % | Juan Flores
Bitácora | 30/02/2026 | 06/03/26 | N/A | Guardar respaldos en la nube para evitar pérdida de información | 100 % | Mateo Tabares

SEMESTRE INTEGRADOR | CÓDIGO | FI-F-001
BITÁCORA | VERSIÓN | 2

## ANÁLISIS DE CAUSA RAÍZ DESAFÍOS ENCONTRADOS:

Durante la semana número ocho, el desarrollo del proyecto se llevó a cabo con normalidad, cumpliendo con las actividades programadas y sin presentarse inconvenientes relevantes.

## Posteriormente, en la semana nueve, se decidió suspender temporalmente las pruebas del

sistema electrónico, con el objetivo de enfocar los esfuerzos en la implementación y optimización de la lectura de códigos QR.

## EVIDENCIA (FOTOGRAFÍA Y ENLACE A REPOSITORIO):

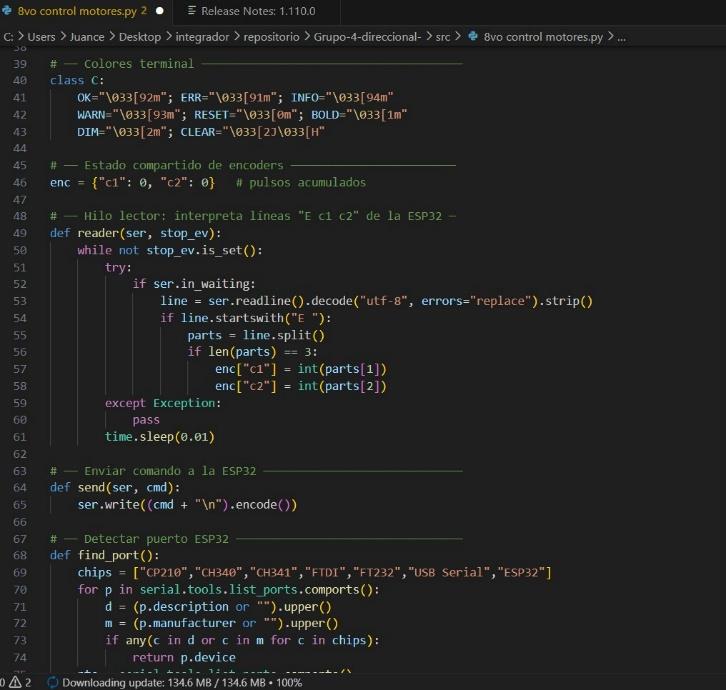
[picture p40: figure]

Código pruebas electrónicas motores (https://github.com/kchala12/Grupo-4-direccional-/blob/main/src/8vo%20control%20motores.py)

MATERIALES | CANTIDA D | UNIDAD DE MEDIDA | COSTO UNITARI O SIN IVA | COSTO UNITARIO + IVA | COSTO TOTAL | JUSTIFICACIÓN
Federico Gómez Lotero | 40 | Horas | $1.400.000 | | $1.400.000 | Encargado de la detección de obstáculos

SEMESTRE INTEGRADOR | CÓDIGO | FI-F-001
BITÁCORA | VERSIÓN | 2
Juan Sebastián Flórez Molina | 40 | Horas | $1.400.000 | $1.400.000 | Encargado de la Detección de códigos QR
Mateo Tabares Gil | 40 | Horas | $1.400.000 | $1.400.000 | Encargado de la bitácora y diseño de acta
Kevin Andrés Chala Gonzalez | 40 | Horas | $1.400.000 | | $1.400.000 | Encargado de las pruebas electrónicas del vehículo
Tatiana Oviedo | 8 | Horas | $1.200.000 | | $1.200.000 | Consultas para diseño de bitácoras y actas
Carlos Andrés Rodríguez Pérez | 12 | Horas | $1.560.000 | | $1.560.000 | Consultas para Desarrollo de uso de la cámara
Edward Andrés Gonzalez Ríos | 12 | Horas | $2.280.000 | | $2.280.000 | Consultas para diseño electrónico
Espacio del laboratorio | 40 | Horas | $208.772 | $254.600 | $254.600 | Espacio para el desarrollo del proyecto
COMPROMISOS | RESPONSABLE | FECHA DE INICIO | FECHA FIN | APRENDIZAJES CLAVE
El equipo se compromete a acabar el código de detección de QR | Juan Florez | 06/04/2026 | 17/04/2026

SEMESTRE INTEGRADOR | CÓDIGO | FI-F-001
BITÁCORA | VERSIÓN | 2

## OBSERVACIONES DOCENTES

OBSERVACIÓN | FECHA | DOCENTE

## CONTROL DE CAMBIOS ESPACIO SOLO PARA CAMBIOS DEL FORMATO

## RESPONSABLE DEL CAMBIO

JUSTIFICACIÓN DEL CAMBIO | DESCRIPCIÓN DEL
| CAMBIO

## FECHA DE CAMBIO

## NÚMERO DEL CAMBIO

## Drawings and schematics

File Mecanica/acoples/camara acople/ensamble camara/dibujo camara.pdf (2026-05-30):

24

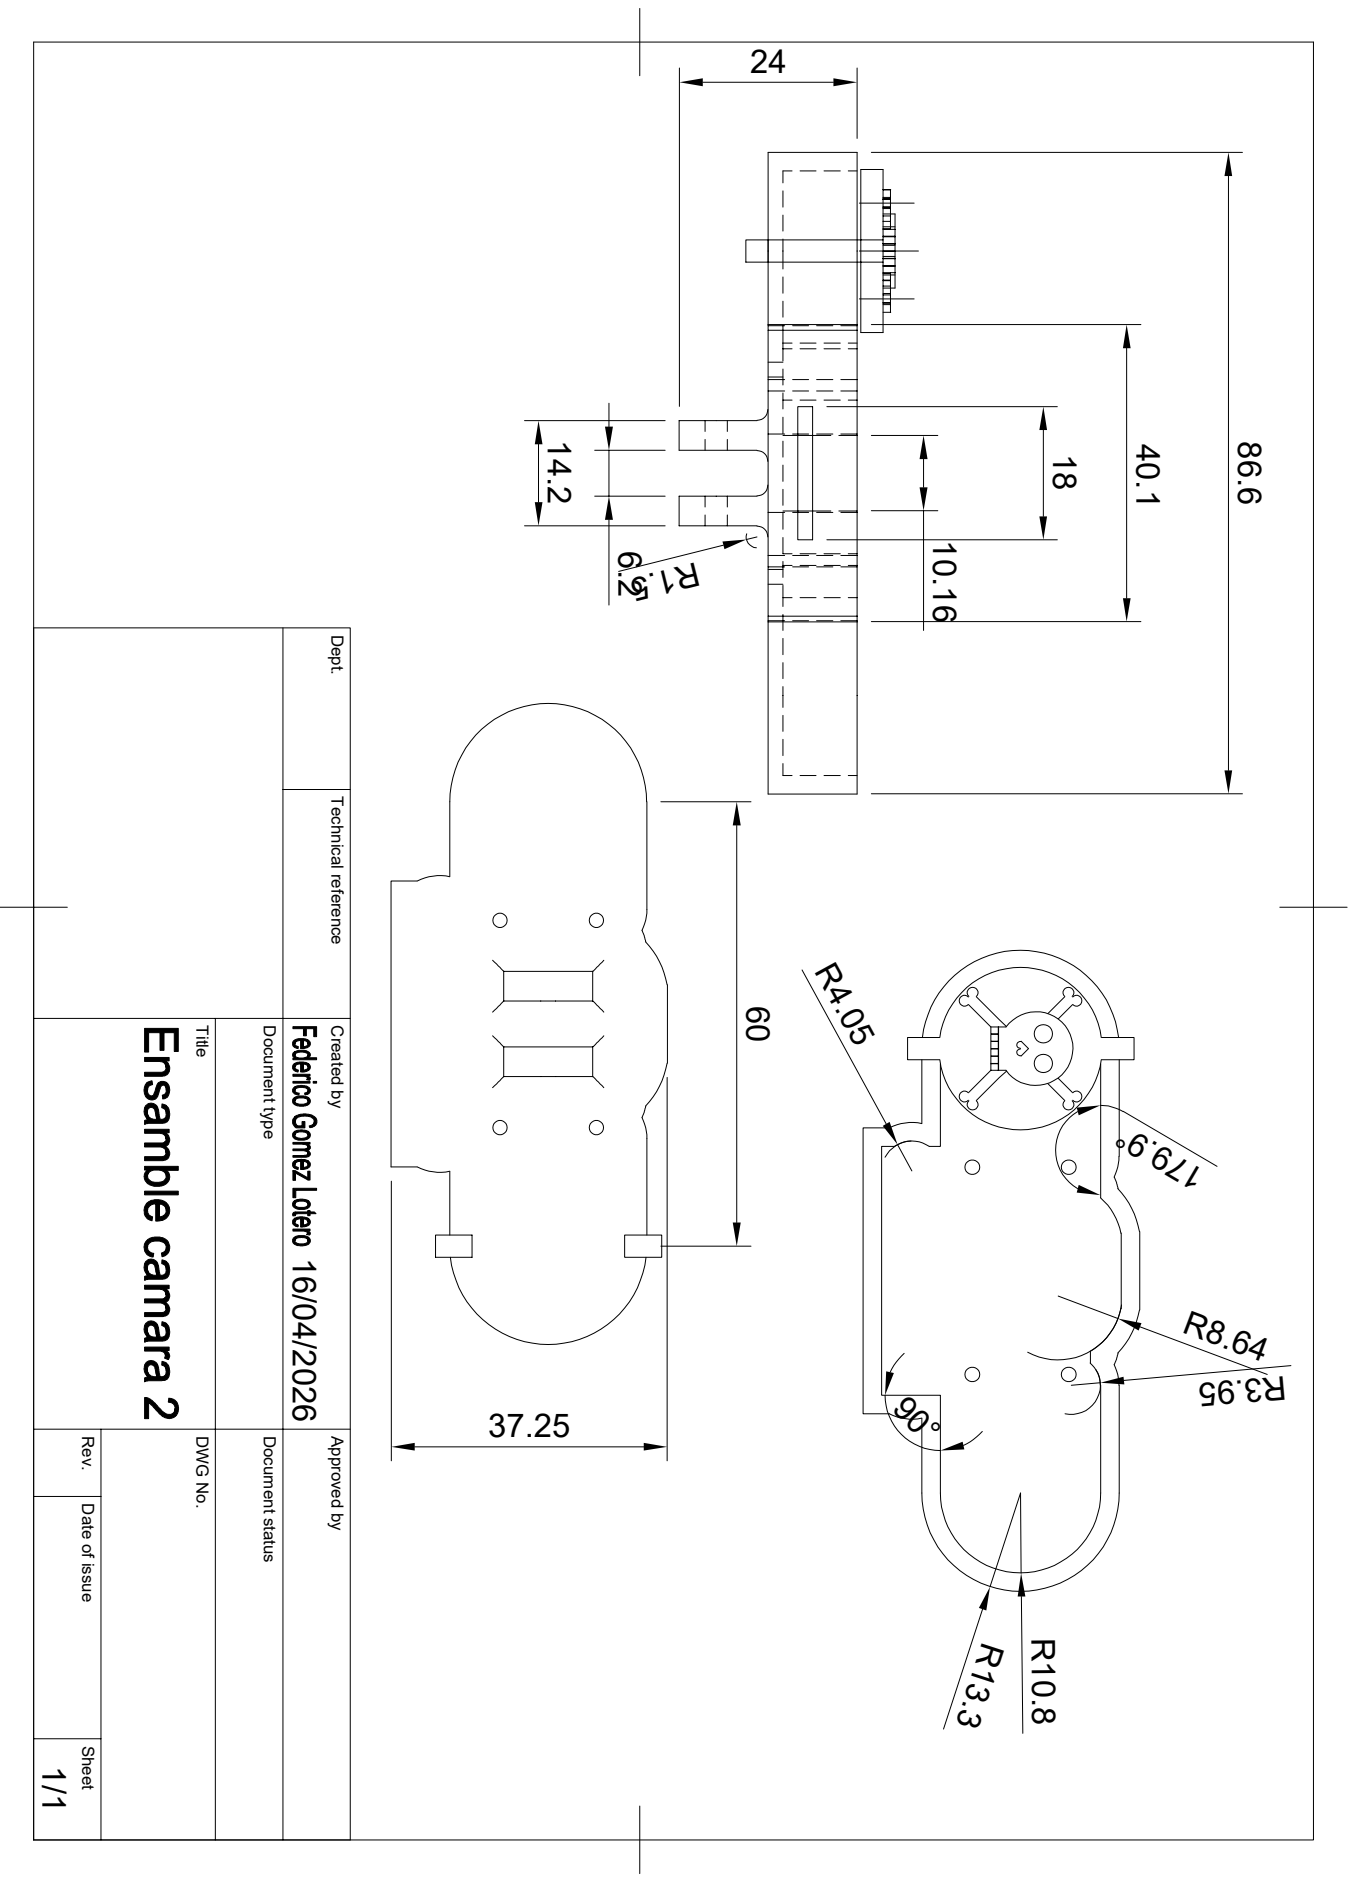
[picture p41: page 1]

Dept. Technical reference Created by Approved by Title DWG No. Document type Document status Rev. Date of issue Sheet 16/04/2026 1/1 86.6

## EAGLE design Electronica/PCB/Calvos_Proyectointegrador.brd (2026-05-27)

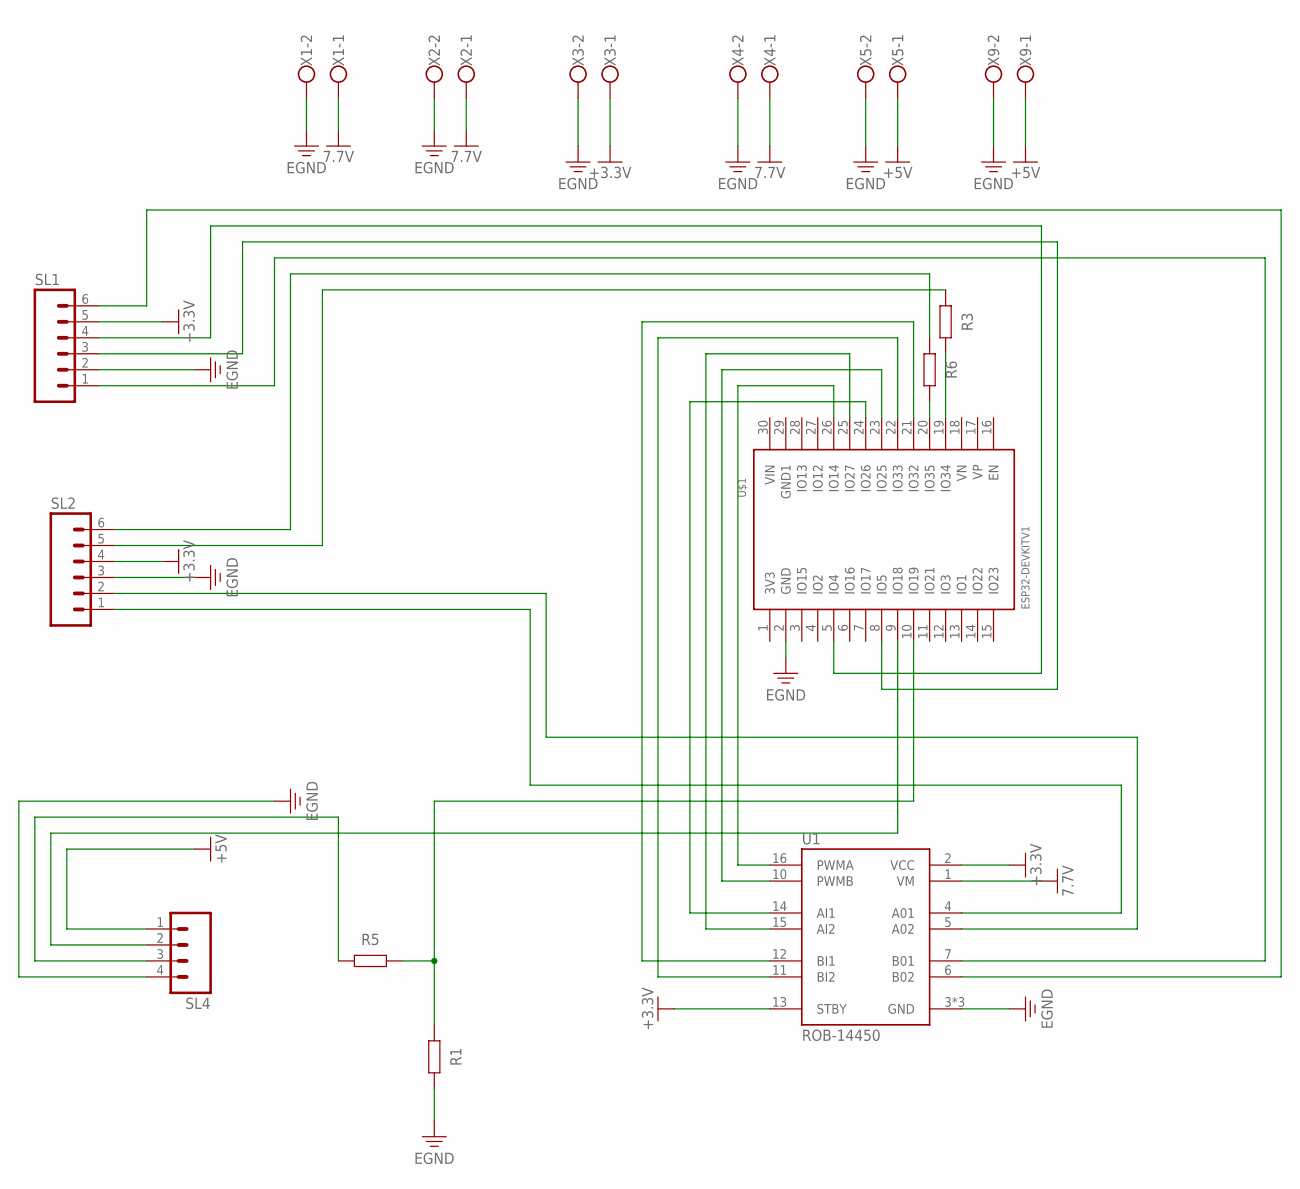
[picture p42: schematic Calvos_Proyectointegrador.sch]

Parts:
R1, R3, R5, R6: R_AXIAL-7.2MM-PITCH; RESAD724W46L381D178B
SL1, SL2: M06; 06P
SL4: M04; 04P
U1: ROB-14450; MODULE_ROB-14450
U$1: ESP32DEVKITV1; ESP32-DEVKITV1
X1, X2, X3, X4, X5, X9: W237-102

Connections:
7.7V: U1.1 (VM), X1.1, X2.1, X4.1
+3.3V: SL1.5, SL2.4, U1.2 (VCC), U1.13 (STBY), X3.1
+5V: SL4.1, X5.1, X9.1
EGND: R1.2, SL1.2, SL2.3, SL4.4, U1.3 (GND), U1.8 (GND), U1.9 (GND), U$1.2 (GND), X1.2, X2.2, X3.2, X4.2, X5.2, X9.2
unnamed: SL1.6, U1.6 (B02)
unnamed: U1.16 (PWMA), U$1.26 (IO14)
unnamed: U1.10 (PWMB), U$1.23 (IO25)
unnamed: U1.15 (AI2), U$1.25 (IO27)
unnamed: U1.14 (AI1), U$1.24 (IO26)
unnamed: U1.12 (BI1), U$1.21 (IO32)
unnamed: U1.11 (BI2), U$1.22 (IO33)
unnamed: SL1.4, U$1.5 (IO4)
unnamed: SL1.3, U$1.8 (IO5)
unnamed: SL1.1, U1.7 (B01)
unnamed: R6.1, SL2.6
unnamed: R3.1, SL2.5
unnamed: SL2.2, U1.5 (A02)
unnamed: SL2.1, U1.4 (A01)
unnamed: SL4.2, U$1.9 (IO18)
unnamed: R1.1, R5.2, U$1.10 (IO19)
unnamed: R5.1, SL4.3
unnamed: R6.2, U$1.20 (IO35)
unnamed: R3.2, U$1.19 (IO34)

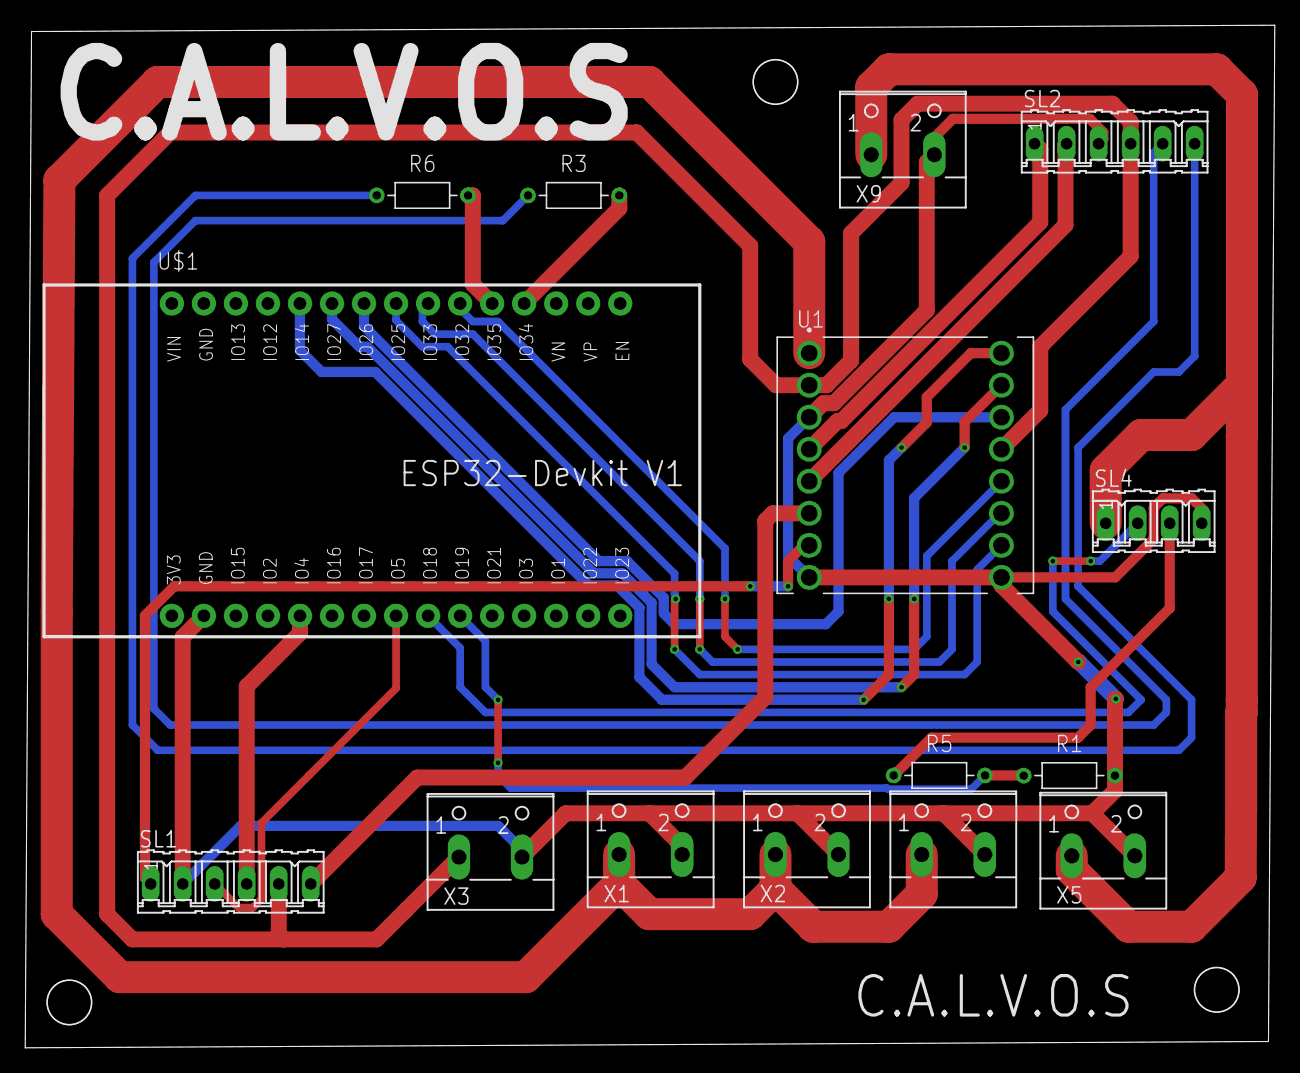
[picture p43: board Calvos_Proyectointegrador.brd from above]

Board: 2 copper layers, 99.1 x 81.1 mm, 15 parts (0 on the bottom side), 23 nets.

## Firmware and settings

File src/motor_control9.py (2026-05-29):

"""
motor_control.py — Librería control motores JGY370
===================================================
Uso como librería:
    import motor_control
    motor_control.iniciar()          # conecta ESP32 y arranca hilos

    motor_control.enviar("f 60")     # adelante al 60%
    motor_control.enviar("b 60")     # atrás
    motor_control.enviar("l 50")     # izquierda
    motor_control.enviar("r 50")     # derecha
    motor_control.enviar("s 0")      # stop
    motor_control.set_velocidades(55, 45, "f")  # PID dirección

    motor_control.enc["c1"]          # pulsos encoder M1
    motor_control.enc["c2"]          # pulsos encoder M2

Modo test standalone:
    python3 motor_control.py
    Comandos: f|b|l|r <vel>  /  f|b|l|r <N> mm  /  f|b|l|r <N> ms  /  s  /  reset  /  exit
"""

import serial
import serial.tools.list_ports
import threading
import time
import math
import sys

# ══════════════════════════════════════════════
#  CALIBRACIÓN
# ══════════════════════════════════════════════
M1_PULSOS_POR_VUELTA = 3816
M2_PULSOS_POR_VUELTA = 2689
RADIO_MM             = 30.0
M1_MM_POR_PULSO      = (2 * math.pi * RADIO_MM) / M1_PULSOS_POR_VUELTA
M2_MM_POR_PULSO      = (2 * math.pi * RADIO_MM) / M2_PULSOS_POR_VUELTA

# ══════════════════════════════════════════════
#  PARÁMETROS PID VELOCIDAD
# ══════════════════════════════════════════════
CTRL_KP             = 1.0
CTRL_INTERVALO_S    = 0.1
CTRL_CORRECCION_MAX = 20

# ══════════════════════════════════════════════
#  ESTADO INTERNO
# ══════════════════════════════════════════════
enc = {"c1": 0, "c2": 0}

_pid = {
    "activo":   False,
    "vel_base": 50,
    "dir":      "f",
}

_ser: serial.Serial | None = None
_ser_lock = threading.Lock()
_stop_ev: threading.Event | None = None

class C:
    OK="\033[92m"; ERR="\033[91m"; INFO="\033[94m"
    RESET="\033[0m"; BOLD="\033[1m"; DIM="\033[2m"

_DIRS_PID = ("f", "b")


# ══════════════════════════════════════════════
#  COMUNICACIÓN
# ══════════════════════════════════════════════
def enviar(cmd: str):
    """Envía un comando a la ESP32. Formato: 'f 60', 'b 50', 's 0', etc."""
    with _ser_lock:
        if _ser and _ser.is_open:
            try:
                _ser.write((cmd.strip() + "\n").encode("utf-8"))
            except Exception:
                pass

def set_velocidades(vel_izq: int, vel_der: int, dir_letra: str):
    """Velocidades independientes por motor para el PID de dirección."""
    enviar(f"pid {vel_izq} {vel_der} {dir_letra}")


# ══════════════════════════════════════════════
#  HILOS INTERNOS
# ══════════════════════════════════════════════
def _hilo_lector(stop_ev):
    while not stop_ev.is_set():
        try:
            with _ser_lock:
                hay = _ser.in_waiting if _ser else 0
            if hay:
                with _ser_lock:
                    linea = _ser.readline().decode("utf-8", errors="replace").strip()
                if linea.startswith("E "):
                    p = linea.split()
                    if len(p) >= 3:
                        enc["c1"] = int(p[1])
                        enc["c2"] = int(p[2])
        except Exception:
            pass
        time.sleep(0.01)


def _hilo_controlador(stop_ev):
    t0 = 0.0; p0c1 = 0; p0c2 = 0
    tasa1 = 0.0; tasa2 = 0.0

    while not stop_ev.is_set():
        time.sleep(CTRL_INTERVALO_S)

        if not _pid["activo"]:
            t0 = 0.0; tasa1 = 0.0; tasa2 = 0.0
            continue

        if t0 == 0.0:
            t0 = time.time(); p0c1 = enc["c1"]; p0c2 = enc["c2"]
            continue

        dt = time.time() - t0
        r1 = abs(enc["c1"] - p0c1)
        r2 = abs(enc["c2"] - p0c2)

        if tasa1 == 0.0 and r1 > 0: tasa1 = r1 / dt
        if tasa2 == 0.0 and r2 > 0: tasa2 = r2 / dt
        if tasa1 == 0.0 or tasa2 == 0.0: continue

        e1 = r1 - tasa1 * dt
        e2 = r2 - tasa2 * dt
        c1 = max(-CTRL_CORRECCION_MAX, min(CTRL_CORRECCION_MAX, CTRL_KP * e1))
        c2 = max(-CTRL_CORRECCION_MAX, min(CTRL_CORRECCION_MAX, CTRL_KP * e2))
        base = _pid["vel_base"]
        m1   = int(max(0, min(100, base - c1)))
        m2   = int(max(0, min(100, base - c2)))

        if _pid["dir"]:
            enviar(f"pid {m1} {m2} {_pid['dir']}")


# ══════════════════════════════════════════════
#  CONEXIÓN
# ══════════════════════════════════════════════
def _buscar_puerto():
    chips = ["CP210","CH340","CH341","FTDI","FT232","USB Serial","ESP32"]
    for p in serial.tools.list_ports.comports():
        d = (p.description or "").upper()
        m = (p.manufacturer or "").upper()
        if any(c in d or c in m for c in chips):
            return p.device
    pts = serial.tools.list_ports.comports()
    return pts[0].device if pts else None


def iniciar(port=None, baud=115200):
    """Conecta a la ESP32 y arranca hilos. Retorna True si tuvo éxito."""
    global _ser, _stop_ev

    puerto = port or _buscar_puerto()
    if not puerto:
        print(f"{C.ERR}[MOTORES] ESP32 no encontrada.{C.RESET}")
        return False
    try:
        _ser = serial.Serial(puerto, baudrate=baud, timeout=1)
        print(f"{C.OK}[MOTORES] Conectado: {puerto}{C.RESET}")
    except serial.SerialException as e:
        print(f"{C.ERR}[MOTORES] {e}{C.RESET}")
        return False

    time.sleep(2)
    _ser.reset_input_buffer()
    _stop_ev = threading.Event()
    threading.Thread(target=_hilo_lector,      args=(_stop_ev,), daemon=True).start()
    threading.Thread(target=_hilo_controlador, args=(_stop_ev,), daemon=True).start()
    return True


def detener():
    """Para hilos y cierra serial."""
    if _stop_ev:
        _stop_ev.set()
    _pid["activo"] = False
    try:
        enviar("s 0")
        time.sleep(0.1)
    except Exception:
        pass
    if _ser and _ser.is_open:
        _ser.close()
    print(f"{C.INFO}[MOTORES] Desconectado.{C.RESET}")


# ══════════════════════════════════════════════
#  MODO TEST
# ══════════════════════════════════════════════
def _modo_test():
    vel = 50
    print(f"""{C.BOLD}
╔══════════════════════════════════════════════╗
║  MODO TEST MOTORES                           ║
║  f|b|l|r <vel>      movimiento indefinido    ║
║  f|b|l|r <N> mm     distancia en mm         ║
║  f|b|l|r <N> ms     tiempo en ms            ║
║  s                  stop                    ║
║  vel <0-100>        velocidad global        ║
║  reset              encoders a cero         ║
║  exit               volver al menú          ║
╚══════════════════════════════════════════════╝{C.RESET}
""")

    while True:
        try:
            cmd = input(f"{C.BOLD}test>{C.RESET} ").strip().lower()
        except (EOFError, KeyboardInterrupt):
            break

        if not cmd: continue
        if cmd in ("exit", "quit"): break

        p = cmd.split()
        letra = p[0]

        if letra == "s":
            _pid["activo"] = False
            enviar("s 0")
            print(f"  {C.OK}Stop.{C.RESET}")

        elif letra == "reset":
            enviar("reset 0")
            print(f"  {C.OK}Encoders reseteados.{C.RESET}")

        elif letra == "vel":
            if len(p) == 2:
                try:
                    vel = int(p[1]); _pid["vel_base"] = vel
                    print(f"  {C.OK}Velocidad: {vel}%{C.RESET}")
                except ValueError:
                    print(f"  {C.ERR}Número inválido.{C.RESET}")

        elif letra in ("f","b","l","r"):
            if len(p) == 1:
                # indefinido
                if letra in _DIRS_PID:
                    _pid["dir"] = letra; _pid["vel_base"] = vel; _pid["activo"] = True
                enviar(f"{letra} {vel}")
                print(f"  {C.OK}{letra} al {vel}% — 's' para parar{C.RESET}")

            elif len(p) == 3:
                try: n = int(p[1])
                except ValueError:
                    print(f"  {C.ERR}Número inválido.{C.RESET}"); continue
                unidad = p[2]

                if unidad == "mm":
                    a1, a2 = enc["c1"], enc["c2"]
                    o1, o2 = n/M1_MM_POR_PULSO, n/M2_MM_POR_PULSO
                    if letra in _DIRS_PID:
                        _pid["dir"]=letra; _pid["vel_base"]=vel; _pid["activo"]=True
                    enviar(f"{letra} {vel}")
                    print(f"  {C.OK}{letra} → {n} mm{C.RESET}")
                    while True:
                        if abs(enc["c1"]-a1)>=o1 and abs(enc["c2"]-a2)>=o2:
                            _pid["activo"]=False; enviar("s 0")
                            d1,d2=enc["c1"]-a1,enc["c2"]-a2
                            print(f"  Alcanzado. M1:{d1:+d}p/{d1*M1_MM_POR_PULSO:+.1f}mm  M2:{d2:+d}p/{d2*M2_MM_POR_PULSO:+.1f}mm")
                            break
                        time.sleep(0.02)

                elif unidad == "ms":
                    a1, a2 = enc["c1"], enc["c2"]
                    if letra in _DIRS_PID:
                        _pid["dir"]=letra; _pid["vel_base"]=vel; _pid["activo"]=True
                    enviar(f"{letra} {vel}")
                    print(f"  {C.OK}{letra} → {n} ms{C.RESET}")
                    time.sleep(n/1000.0)
                    _pid["activo"]=False; enviar("s 0")
                    d1,d2=enc["c1"]-a1,enc["c2"]-a2
                    print(f"  Cumplido. M1:{d1:+d}p/{d1*M1_MM_POR_PULSO:+.1f}mm  M2:{d2:+d}p/{d2*M2_MM_POR_PULSO:+.1f}mm")
                else:
                    print(f"  {C.ERR}Unidad inválida: usa mm o ms{C.RESET}")
            else:
                print(f"  {C.ERR}Uso: {letra} <vel>  |  {letra} <N> mm  |  {letra} <N> ms{C.RESET}")
        else:
            print(f"  {C.ERR}Comando no reconocido: '{letra}'{C.RESET}")


# ══════════════════════════════════════════════
#  STANDALONE
# ══════════════════════════════════════════════
if __name__ == "__main__":
    import argparse
    ap = argparse.ArgumentParser()
    ap.add_argument("--port", default=None)
    ap.add_argument("--baud", type=int, default=115200)
    args = ap.parse_args()
    if not iniciar(port=args.port, baud=args.baud):
        sys.exit(1)
    try:
        _modo_test()
    finally:
        detener()

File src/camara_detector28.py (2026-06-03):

"""
camara_detector.py — Librería detector de pista
"""

import threading
import time
import json
import cv2
import numpy as np
from http.server import HTTPServer, BaseHTTPRequestHandler
from socketserver import ThreadingMixIn
from pupil_apriltags import Detector as AprilTagDetector

try:
    from picamera2 import Picamera2
    PICAMERA_DISPONIBLE = True
except ImportError:
    PICAMERA_DISPONIBLE = False

MAPA_TAGS = {
    1:  {"tipo": "carga",       "numero": 1, "posicion": "entrada"},
    2:  {"tipo": "mision",      "destino": 1, "carril": 2},
    3:  {"tipo": "mision",      "destino": 2, "carril": 3},
    4:  {"tipo": "mision",      "destino": 3, "carril": 3},
    5:  {"tipo": "informativo", "opciones": {"carril 2": "giro izquierda", "carril 3": "seguir recto"}},
    6:  {"tipo": "descarga",    "numero": 1, "posicion": "entrada"},
    7:  {"tipo": "descarga",    "numero": 2, "posicion": "entrada"},
    8:  {"tipo": "descarga",    "numero": 3, "posicion": "entrada"},
    9:  {"tipo": "informativo", "opciones": {"carril 1": "girar izquierda", "carril 3": "girar derecha"}},
    10: {"tipo": "informativo", "carril_actual": 2, "destinos": {
            1: {"carril": 1, "movimiento": "seguir recto"},
            2: {"carril": 3, "movimiento": "derecha"},
            3: {"carril": 3, "movimiento": "derecha"},
        }
    },
}

C_LINEA_ROJA     = (0,   0,   220)
C_LINEA_AMARILLA = (0,   210, 210)
C_CENTRO         = (200,   0, 200)
C_QR             = (255,   0,   0)
C_OBSTACULO      = (0,   0,   255)
C_ALERTA         = (0,   0,   255)
C_HUD            = (255, 255, 255)

ROI_INICIO = 0.60
ROI_ALTO   = 0.40

# ══════════════════════════════════════════════
#  PUNTO DE REFERENCIA LÍNEA ÚNICA
# ══════════════════════════════════════════════
OFFSET_CENTRO_DEFAULT = 50   # valor por defecto — ajustable desde principal
OFFSET_CENTRO         = OFFSET_CENTRO_DEFAULT
REF_SOLO_AMARILLA     = 0.25
REF_SOLO_ROJA_RECTA   = 0.95
REF_SOLO_ROJA_CURVA   = 0.50
UMBRAL_INCLINACION    = 90

ZONA_OBSTACULO_ANCHO = 0.6
ZONA_OBSTACULO_DESDE = 0.70
ZONA_OBSTACULO_HASTA = 0.95
UMBRAL_BLOQUEO       = 0.35

OBS_FRAMES      = 60
OBS_UMBRAL_DIFF = 90
OBS_AREA_MIN    = 800

OBS_FRAMES_ACTIVAR = 3
OBS_FRAMES_LIBERAR = 8

AREA_MIN_LINEA = 50

ultimo_frame: bytes | None = None
frame_lock   = threading.Lock()

codigos_leidos: set[str] = set()
codigos_lock = threading.Lock()

estado = {
    "obstaculo_detectado": False,
    "error_linea":         None,
    "ultimo_tag":          None,
    "ignorar_roja":        False,
    "solo_roja":           False,
    "en_curva":            False,
}
estado_lock = threading.Lock()

_fondo_ref   = None
_fondo_count = 0
_fondo_lock  = threading.Lock()
_obs_contador = 0


def resetear_fondo():
    global _fondo_ref, _fondo_count
    with _fondo_lock:
        _fondo_ref   = None
        _fondo_count = 0
    print("[CAMARA] Recalibrando fondo...")


def _mask_lineas(hsv):
    m_r1 = cv2.inRange(hsv, np.array([0,   60,  50]), np.array([10,  255, 255]))
    m_r2 = cv2.inRange(hsv, np.array([160,  60,  50]), np.array([180, 255, 255]))
    m_a  = cv2.inRange(hsv, np.array([18,  100, 100]), np.array([35,  255, 255]))
    return cv2.bitwise_or(cv2.bitwise_or(m_r1, m_r2), m_a)


def _centroide(mask, offset_y=0):
    cnts, _ = cv2.findContours(mask, cv2.RETR_EXTERNAL, cv2.CHAIN_APPROX_SIMPLE)
    if not cnts:
        return None, None, None
    c = max(cnts, key=cv2.contourArea)
    if cv2.contourArea(c) < AREA_MIN_LINEA:
        return None, None, None
    M = cv2.moments(c)
    if M["m00"] == 0:
        return None, None, None
    cx = int(M["m10"] / M["m00"])
    cy = int(M["m01"] / M["m00"]) + offset_y
    return cx, cy, c


def detectar_y_dibujar_lineas(frame):
    h, w   = frame.shape[:2]
    oy     = int(h * ROI_INICIO)
    oy_fin = min(h, oy + int(h * ROI_ALTO))
    roi    = frame[oy:oy_fin, :]
    hsv    = cv2.cvtColor(roi, cv2.COLOR_BGR2HSV)
    kernel = cv2.getStructuringElement(cv2.MORPH_RECT, (7, 7))

    mask_r1 = cv2.inRange(hsv, np.array([0,   120,  70]), np.array([10,  255, 255]))
    mask_r2 = cv2.inRange(hsv, np.array([170, 120,  70]), np.array([180, 255, 255]))
    mask_r  = cv2.morphologyEx(cv2.bitwise_or(mask_r1, mask_r2), cv2.MORPH_CLOSE, kernel)
    mask_a  = cv2.morphologyEx(
        cv2.inRange(hsv, np.array([18, 100, 100]), np.array([35, 255, 255])),
        cv2.MORPH_CLOSE, kernel)

    with estado_lock:
        ignorar = estado["ignorar_roja"]

    if ignorar:
        cx_r, cy_r, cnt_r = None, None, None
    else:
        cx_r, cy_r, cnt_r = _centroide(mask_r, oy)

    mask_a_izq = mask_a.copy()
    mask_a_izq[:, w // 2:] = 0
    cx_a, cy_a, cnt_a = _centroide(mask_a_izq, oy)

    if cnt_r is not None:
        cv2.drawContours(frame, [cnt_r + np.array([0, oy])], -1, C_LINEA_ROJA, 2)
        cv2.circle(frame, (cx_r, cy_r), 7, C_LINEA_ROJA, -1)
        cv2.putText(frame, "ROJA", (cx_r+10, cy_r), cv2.FONT_HERSHEY_SIMPLEX, 0.5, C_LINEA_ROJA, 2)

    if cnt_a is not None:
        cv2.drawContours(frame, [cnt_a + np.array([0, oy])], -1, C_LINEA_AMARILLA, 2)
        cv2.circle(frame, (cx_a, cy_a), 7, C_LINEA_AMARILLA, -1)
        cv2.putText(frame, "AMARILLO", (cx_a+10, cy_a), cv2.FONT_HERSHEY_SIMPLEX, 0.5, C_LINEA_AMARILLA, 2)

    roi_h     = roi.shape[0]
    FRANJAS_P = (0.10, 0.25, 0.40, 0.55)
    franjas   = [int(roi_h * p) for p in FRANJAS_P]

    def _x_promedio_franjas(mask, franjas):
        xs = []
        for fy in franjas:
            if fy >= mask.shape[0]:
                continue
            pixeles = np.where(mask[fy, :] > 0)[0]
            if len(pixeles) > 0:
                xs.append(int(np.mean(pixeles)))
        return int(np.mean(xs)) if xs else None

    fx_r = None if ignorar else _x_promedio_franjas(mask_r, franjas)
    fx_a = _x_promedio_franjas(mask_a_izq, franjas)

    if fx_r is None and cx_r is not None:
        fx_r = cx_r
    if fx_a is None and cx_a is not None:
        fx_a = cx_a

    ref_sup = oy + franjas[0]
    ref_inf = oy + franjas[-1]
    cv2.line(frame, (0, ref_sup), (w, ref_sup), (50, 50, 50), 1)
    cv2.line(frame, (0, ref_inf), (w, ref_inf), (50, 50, 50), 1)
    cv2.putText(frame, "ref sup", (4, ref_sup-4), cv2.FONT_HERSHEY_SIMPLEX, 0.35, (50, 50, 50), 1)
    cv2.putText(frame, "ref inf", (4, ref_inf-4), cv2.FONT_HERSHEY_SIMPLEX, 0.35, (50, 50, 50), 1)

    def _fitline_roja():
        cnts_f, _ = cv2.findContours(mask_r, cv2.RETR_EXTERNAL, cv2.CHAIN_APPROX_SIMPLE)
        if not cnts_f:
            return 0, 0, 1, 0, 0
        cnt_mayor = max(cnts_f, key=cv2.contourArea)
        if len(cnt_mayor) < 5:
            return 0, 0, 1, 0, 0
        line = cv2.fitLine(cnt_mayor, cv2.DIST_L2, 0, 0.01, 0.01)
        vx, vy = float(line[0]), float(line[1])
        x0, y0 = int(line[2]), int(line[3]) + oy
        incl = abs(vx) / (abs(vy) + 0.001) * 100
        return incl, vx, vy, x0, y0

    incl_r, vx_r, vy_r, x0_r, y0_r = _fitline_roja()
    en_curva = (incl_r > UMBRAL_INCLINACION) and (fx_r is not None)
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

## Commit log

2026-02-23 Creacion de carpetas de mecanica documentacion y codigo
2026-03-04 Imagenes de Prueba semana 4 y 5
2026-03-05 codigo de prueba para motores
2026-03-06 segundo codigo de prubas para motor
2026-03-11 Prueba motores 3.1
2026-03-11 partes mecanicas del robot
    [RaspberryPi.f3d, acople motor.f3z, camara acople.f3d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]
2026-03-13 prueba de motores 4
2026-03-16 prueba motores #5
2026-03-20 control de motores 6
2026-03-20 control de motores 7
2026-03-21 Subida de pruebas bitácora semana 6 y 7
2026-03-21 Delete Documentacíon/Circuito luego de la prueba de autonomia.jpeg
    Imagen equivocada
2026-03-21 corrección de la imagen anterior
2026-03-21 Dibujo CAD
2026-03-25 Cronograma del sistema
    [Cronograma-v2.xlsx]
2026-03-25 camara y diseños cad
2026-03-25 Informe de Actividades
2026-03-25 Informe de Avance del GRUPO
2026-03-26 documentacion completa mecanica
    [RaspberryPi.f3d, acople motor.f3z, acople motor.stl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]
2026-03-26 organización de pruebas
2026-03-27 8vo control de motores
2026-03-28 Imágenes de errores sucedidos
2026-03-28 Delete Documentacíon/Circuito luego de la prueba.jpeg
    Eliminado debido a q esta mal puesto
2026-03-28 Delete Documentacíon/Reemplazo del circuito.jpeg
    Eliminado debido a que esta mal puesto
2026-03-28 Delete Documentacíon/base.jpeg
    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
2026-03-28 Delete Documentacíon/motor defectuoso.jpeg
    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
2026-03-28 Delete Documentacíon/motor funcional.mp4
    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
2026-03-28 organizacion de archivos
2026-04-07 noveno control de motores
2026-04-09 decimo control de motores
2026-04-10 11vo control de motores
2026-04-10 doceavo control de motores
2026-04-14 Delete Documentacíon/Bitacoras/Bitacora Semana 8 y 9.docx
    Se Elimina la versión con solo el planeado y se reemplaza por la versión con ejecución.
2026-04-14 Añadir bitácoras
    Se añaden las bitácoras de las semanas 8 y 9 y el proyectado de las semanas 10 y 11
2026-04-16 nueva version de motores y camara
2026-04-16 actualizacion parte de mecanica
    [Ensamble camara 2.f3z, Ensamble camara 2.stl, base camara.f3d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]
2026-04-17 Create Readme.md
    Creacion de una nueva carpeta
2026-04-24 codigo de calibracion
2026-04-24 actualizaciones por motor nuevo
2026-04-24 actualizacion de deteccion de lineas camara
2026-04-24 fix a la deteccion de obstaculos y lineas
    [camara_detector8.py]
2026-04-30 cambio en la detección de obstaculos
2026-04-30 segundo ajuste de deteccion de obstaculos
2026-05-01 cambio a zona de deteccion de obstaculos
2026-05-01 cambios a la deteccion de obstaculos y fondo
2026-05-05 cambio de hsv a rgb
2026-05-05 correccion de cambio a rgb
2026-05-12 deteccion de qr
2026-05-12 dibujos con cotas
    [atras abajo.dxf, atras arriba.dxf, base camara 2.stl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]
2026-05-12 primera calibracion para descarga 1
2026-05-12 Update README.md
    Actualización de títulos
2026-05-13 actualizacion de acciones en base a qr
2026-05-15 mecanica lista
    [caja ultra.stl, pared de atras inferior.dxf, pared de atras superior.dxf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]
2026-05-16 actualizacion de deteccion de curva
2026-05-18 Delete Documentacíon/Manual de Usuario/Manual de usuario IEEE.docx
    Rememplazo a pdf
2026-05-20 re organizacion de documentos
2026-05-20 Subida de material
2026-05-20 Delete Documentacíon/Poster_AGV_Robot (1).pptx.png
    Se subió la versión final en otra carpeta
2026-05-21 Delete Documentacíon/Presentaciones/JUNIO 2026 (2).pdf
    Errores de presentación
2026-05-21 Matriz de documentos
    [Matriz control documentos (1) (2).xlsx]
2026-05-22 nuevo bucle y sistema de carga
2026-05-26 Delete Electronica/PCB/C.A.L.V.O.S.zip
    Cambio a archivos buenos
2026-05-26 Add files via upload
    Archivos de texto .gbr para diseño pcb
    [copper_bottom.gbr, copper_top.gbr, drill_1_64.xln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]
2026-05-26 actualizacion de puntos de descarga
2026-05-29 cambio de ultrasonico a pines de raspberry, im really fkn tired of writing ts
2026-05-30 nueva parte de la carga
    [atras abajo.dxf, atras arriba.dxf, atras bajo.dxf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]
2026-05-30 Zona de descarga defectuosa
2026-05-30 nuevo diseño
    [Ensamble camara 2.f3z, Ensamble camara 2.stl, Pared 2 nueva.dxf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]
2026-05-30 adicion de IR a deteccion de estaciones
2026-06-02 nueva pared ultra
    [pared ultra.stl, ultra nuevo chiqui.stl]
2026-06-03 actualizacion de emergencia
